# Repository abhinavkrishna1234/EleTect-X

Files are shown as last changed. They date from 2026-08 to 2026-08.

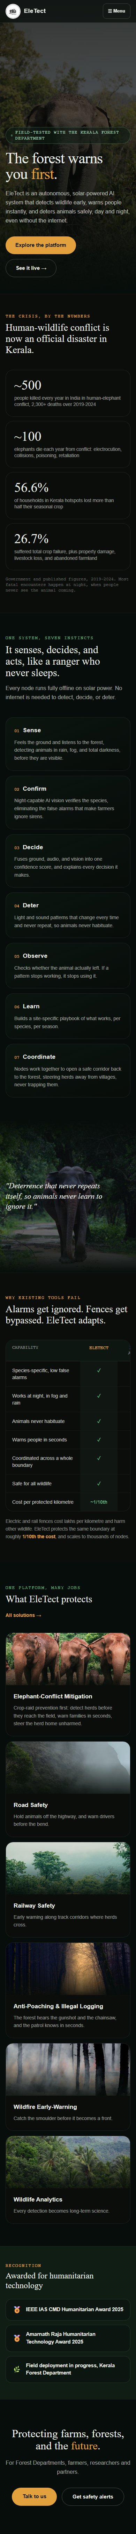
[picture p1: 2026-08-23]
docs/qa/phase2/home-built-mobile.png

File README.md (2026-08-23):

# EleTect X

**Adaptive Physical-AI platform for Human–Elephant Conflict (HEC) mitigation.**

EleTect X is a rugged, solar-powered, autonomous forest-edge node built on the Arduino UNO Q. It detects elephants early through the ground (seismic), confirms with on-device vision, deters with an adaptive, non-habituating light + sound response, alerts rangers, and coordinates with neighbouring nodes to steer wildlife safely — day and night, without cloud dependence.

## Why it's different
- **Seismic-primary, multimodal** detection (all-weather, day/night) — not a camera trap.
- **Adaptive deterrence** that measures outcomes and learns (contextual bandit), avoiding habituation.
- **Distributed coordination** — nodes create safe herding corridors, not random noise.
- **Ultra-low-power** event-driven architecture; weeks of autonomy.
- **Extensible** — optional environmental / fire-risk / anti-poaching pods; road-signage integration.

## Repository layout
| Path | Contents |
|---|---|
| `docs/` | Architecture, hardware, decisions (ADRs), deployment, manufacturing |
| `device/mcu/` | STM32U585 real-time reflex firmware |
| `device/mpu/` | QRB2210 (Debian) cognition: vision, fusion, deterrence, comms |
| `ml/` | Seismic/acoustic/vision model training + eval (off-device) |
| `hardware/` | PCB, CAD/enclosure, wiring |
| `web/backend/` | Supabase schema, RLS, edge functions |
| `web/ingest/` | ChirpStack MQTT → Supabase bridge |
| `web/frontend/` | Ranger dashboard + public marketing site (React PWA) |
| `deployment/` | Field protocols, install guides, logs |
| `scripts/`, `tests/` | Utilities and tests |

## Getting started
See [`CONTEXT.md`](CONTEXT.md) for the project's single source of truth, then [`docs/PROJECT_BLUEPRINT.md`](docs/PROJECT_BLUEPRINT.md) for the execution plan.

## Status
Active development. Architecture frozen; implementation in progress.

## License
Proprietary — see [`LICENSE`](LICENSE).

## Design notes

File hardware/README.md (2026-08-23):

# Hardware

pcb/ (KiCad), cad/ (enclosure STEP/STL + print profiles), wiring/ (pinouts, schematics).

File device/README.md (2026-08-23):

# Device — On-Node Software (Arduino UNO Q)

Everything that runs ON the node. `mcu/` = STM32U585 real-time reflex; `mpu/` = QRB2210 Linux cognition. Fully autonomous — no cloud in the control loop.

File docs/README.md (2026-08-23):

# Documentation

**Hierarchy (top → detail):** `CONTEXT.md` (canonical summary) → `docs/architecture/` + `docs/hardware/` (current design) → `docs/decisions/` (ADRs, the "why") → `docs/deployment/`, `docs/manufacturing/` (operational) → `docs/research/` (kept for reference) → `docs/archive/` (superseded, read-only).

**Rule:** exactly one current document per topic. If two disagree, `CONTEXT.md` wins; reconcile and archive the loser.

## Structure
| Folder | Holds | Status |
|---|---|---|
| `architecture/` | system, physical-AI, software, comms architecture | living |
| `hardware/` | BOM, camera, geophone, power, deterrence, enclosure specs | living |
| `decisions/` | ADRs (numbered), one per significant choice | append-only |
| `deployment/` | field-test protocol, KPIs, DFO, install guide | living |
| `manufacturing/` | DFM, in-house printing, assembly | living |
| `research/` | background studies still worth reading | frozen |
| `archive/` | obsolete / duplicated originals (dated) | read-only |

## Consolidation plan (migrate the existing research .md files)
The research phase produced many overlapping Markdown files. Consolidate as follows (one current doc per topic; everything else archived):

| Target (current) | Merge from |
|---|---|
| `CONTEXT.md` | Final Design Freeze + Pre-Build Optimization (decisions only) |
| `architecture/physical-ai.md` | Physical AI Architecture |
| `architecture/system.md` | Optimized Architecture + Rev B (UNO-Q-centric) + Rev B.1 (carrier-free) |
| `architecture/comms.md` | Connectivity Decision (LoRaWAN IN865) |
| `hardware/bom.md` | FINAL Freeze BOM |
| `hardware/camera.md` | Camera Shopping List + Comparison + IR-LED spec |
| `hardware/geophone.md` | Geophone Deployment Subsystem + Buy List |
| `hardware/deterrence.md` | Speaker Selection + Horn Analysis + Visual Deterrence Subsystem |
| `hardware/enclosure.md` | Concept Validation + Production Enclosure + In-House Manufacturing |
| `deployment/field-plan.md` | 45-Day Contest & Field Plan |
| `decisions/` (ADRs) | one ADR per frozen choice (camera, fusion, learning, comms, audio, geophone AFE) |
| `research/` | Ecological Framework, Confidence-Estimation study, Validation Report |
| `archive/` | all original Gemini deep-research drafts + any superseded review docs (prefix `YYYYMMDD-`) |

**Process:** (1) create the current docs above by lifting only the *decided* content; (2) move every original into `archive/` with a date prefix and a one-line "superseded by …" header; (3) never edit archived files. This yields a single source of truth that stays maintainable.

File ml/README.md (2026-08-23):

# ML — Off-Device Training

Training pipelines + datasets + evaluation. Runs on a PC, NOT the node. `seismic/` + `acoustic/` → **Edge Impulse** exports to `device/mcu/lib`; `vision/` → INT8 model to `device/mpu/models`. Keeps heavy training out of the flashable device code.

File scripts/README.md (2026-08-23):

# Scripts

Build/flash/calibrate/data utilities. No secrets committed.

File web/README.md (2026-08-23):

# Web — Monitoring Web App (off-device, not the control loop)

The Forest-Department web application. `frontend/` React PWA (dashboard + marketing); `backend/` Supabase (schema, RLS, functions); `ingest/` ChirpStack MQTT → Supabase. Renamed from 'cloud' to avoid implying on-device control — the node is fully autonomous; this only monitors/alerts.

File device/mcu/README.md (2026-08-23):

# MCU — STM32U585 (real-time reflex)

Arduino Core on Zephyr, C/C++. Geophone ADC+STA/LTA+**seismic TinyML**, **acoustic anti-poaching
(Edge Impulse, gunshot/chainsaw)**, actuator timing (horn/LED/IR), LoRa MAC, power, safety
rule-gates, watchdog. On-device models live in `lib/` (Edge Impulse SDK export).

## Two build paths — read this before touching either

- **`pio run -e native` / `pio test -e native`** — host-only compile/test harness (ADR 0010).
  Proves the whole `src/` tree builds and links against a small Arduino API shim
  (`hostshim/`), and runs the Unity known-answer tests on the pure cores (`sta_lta.cpp`,
  `rule_gate.cpp`). **This never produces a flashable image.** `hostshim/` is never synced to the
  board.
- **App Lab (or the Arduino App CLI over SSH)** — the only path onto real hardware. Fed by
  `scripts/sync-to-board.sh`, which one-directionally mirrors `src/` (config.h and secrets.h
  included — see the Layout section below on why they live in `src/`, not a separate `include/`)
  into the board's App folder as `sketch/`. Never hand-edit the board's copy — edit here, re-run
  the sync script, then build/flash from App Lab.

## Wiring — bench stand-in (ADS1115 + INA333)

The field geophone (SM-24) and its INA333 instrumentation amp connect to an ADS1115 breakout
today, standing in for the STM32's own internal ADC (ADR 0009 swaps this out via LPBAM once that
Rung lands). Plain jumper wires, not Qwiic — I2C2 is an independent bus from the Qwiic connector's
I2C4.

Pin names below match the actual silkscreen on the two breakout boards in use (INA333: `WCMCU-333`;
ADS1115: `HW-198`) — not the generic IC datasheet pin names, so this table can be followed directly
without translating labels at the bench.

**ADS1115 (`HW-198`) side:**

| Signal | ADS1115 pin (silkscreen) | UNO Q pin | MCU pin |
| --- | --- | --- | --- |
| SDA | `SDA` | D20 | PB11 (I2C2_SDA) |
| SCL | `SCL` | D21 | PB10 (I2C2_SCL) |
| Power | `VDD` | 3V3 | — |
| Ground | `GND` | GND | — |
| Address select | `ADDR` | GND | — (fixes I2C address at `0x48`) |
| Differential input+ | `A0` | — | INA333 `VOUT` |
| Differential input− | `A1` | — | INA333 `UREF` |

**INA333 (`WCMCU-333`) side:**

| Signal | INA333 pin (silkscreen) | Connects to |
| --- | --- | --- |
| Output | `VOUT` | ADS1115 `A0` |
| Reference | `UREF` | ADS1115 `A1` (same function as the datasheet's `REF` pin) |
| Power | `VCC` | 3V3 rail — use this pin, not the board's separate `3.3V` label (see note below) |
| Ground | `GND` | GND rail (either of the board's two `GND` pins) |
| Non-inverting input | `VIN+` | 1 kΩ series resistor → damping-resistor node → geophone lead |
| Inverting input | `VIN-` | 1 kΩ series resistor → damping-resistor node → geophone other lead |

**Unconfirmed:** this board breaks out both `VCC` and a separately labeled `3.3V` pin (also two `GND`
pins, one per edge). Most likely these are the same power/ground nets mirrored on both edges of the
board for breadboard convenience, not two distinct functions — but this is not verified against a
datasheet for this specific clone board. Wire `VCC` (the standard supply-pin name) to 3V3 and leave
the separate `3.3V` pin unconnected; only investigate further if the amp doesn't power up.

Geophone signal path: SM-24 → (1 kΩ damping resistor) → 1 kΩ series resistors → INA333 `VIN+`/
`VIN-` → INA333 → ADS1115 `A0`/`A1` differential pair, rejecting the INA333's bias rail (`UREF`)
rather than reading it as signal.

**Input protection — 1 kΩ in series with each INA333 input.** Between the damping-resistor node and
the INA333's `VIN+`/`VIN-` pins, add a 1 kΩ resistor in each leg. Negligible effect on the signal
(the INA333's input impedance is high enough that this forms an RC corner far above the 2-50 Hz
seismic band), but gives the amp's internal ESD structures some current limiting against a transient
on the buried cable run. Same 1 kΩ value as the damping resistor, already in the kit. This is a
cheap partial mitigation, not a substitute for the still-open TVS/clamp item in
`docs/KNOWN_GAPS.md` — see ADR 0001's 30 Jul addendum.

**Damping resistor — required, not optional.** The SM-24's open-circuit damping is h=0.25
(datasheet), badly underdamped at its 10 Hz resonance: an unshunted coil rings for several cycles
after every footfall, smearing the STA/LTA envelope the trigger detector reads. Wire a **1 kΩ
resistor directly across the SM-24's own two leads**, before the burial cable (not at the INA333
end — cable resistance would otherwise shift the delivered damping away from this calculation).
1 kΩ gives h≈0.69, matching one of the datasheet's own plotted response curves, using
`R_shunt = RtBcfn / (fn × (h_target − h_open)) − Rc` with the SM-24's own
`RtBcfn=6000 Ω·Hz, fn=10 Hz, Rc=375 Ω` against a target h≈0.7. Any resistor from the existing kit
works — tolerance isn't critical here. See ADR 0001 addendum for the full derivation.

**INA333 REF-bias check — do this before wiring the rest.** The geophone's output is a true AC
signal (swings both positive and negative). If the INA333's `UREF` pin is tied to GND instead of a
mid-supply bias (~VCC/2), the negative half of every waveform clips at the rail. Short `VIN+` to
`VIN-`, then run the check: set `GEOPHONE_DEBUG_SINGLE_ENDED_AIN0` to `1` in `src/config.h`,
sync, flash, and read the `[bias-check] raw=<int> volts=<float>` lines the board prints — ~1.65V
on a 3.3V rail means `UREF` is biased correctly and the wiring below is safe to use as-is; a
reading near 0V means it isn't, and needs an external fix before proceeding. Read the console via
**App Lab's own Serial Monitor (in a browser)** — `arduino-app-cli monitor` over SSH does not
deliver serial data on this board; see ADR 0010's 2026-07-30 addendum. Set the flag back to
`0` and re-sync before moving on — it must never read `1` on a node headed for the field
(`src/config.h`'s own bench-only-flags section says the same). Also check this board's `RG`
gain-setting pads (unlabeled in the photo reference for this specific board — look for a small
unpopulated 2-pad footprint near the INA333 chip itself, not on the main 8-pin header) — ~1 kΩ
gives a reasonable starting gain (G≈101) if bare.

**Result (2026-07-30):** `[bias-check] raw≈26890 volts≈1.6806V`, stable across multiple readings —
`UREF` is correctly mid-supply biased and the wiring above is safe to use as-is.

**Seismic waveform capture (Part C2 sensitivity pass).** Separate from the REF-bias check above:
set `SEISMIC_DEBUG_VERBOSE` to `1` to get a periodic `[seismic]` sta/lta/ratio line plus a
`[window]` CSV volts dump on every `[trigger]` event, then render the dumps with
`python scripts/plot_seismic_window.py <saved-console-log> --out-dir <dir>`. Same flag discipline
as above — back to `0` and re-sync once the capture session is done.

**Live seismic plot (pitch/demo tool, not the Part C2 pass above).** Set both
`SEISMIC_DEBUG_STREAM_RAW` and `SEISMIC_DEBUG_VERBOSE` to `1`, sync, flash, then run
`python scripts/live_seismic_plot.py --port <COM port>` (or `--file <log>` / `-` for stdin,
depending on which console transport is reachable — see the script's own docstring; only App
Lab's browser Serial Monitor is confirmed to deliver bytes at all, per ADR 0010's 2026-07-30
addendum) for a live two-panel view: raw geophone volts on top, STA/LTA ratio with the
`STA_LTA_TRIGGER_RATIO` (4.0) line on the bottom. The bottom panel does not advance for
`EVENT_MAX_MS` + `COOLDOWN_MS` (about 35 s today) after a trigger, since `[seismic]` only
prints while the state machine is in `kSensing` — time a recording around that gap rather than
expecting a continuous trace across an event. Same flag discipline as above — both flags back
to `0` and re-sync once the recording session is done.

**Known open item (`docs/KNOWN_GAPS.md`):** whether `Wire` or `Wire1` is actually the Arduino Core
mapping for I2C2 (D20/D21) on this board has not been confirmed on hardware. `config.h` defaults to
`Wire`. If the geophone never reads (`geophone_ok()` stays false, or `report_system_status`'s
`geophone_ok` field never sets), try `Wire1` first.

## Build / test

```powershell
cd device\mcu
pio test -e native      # both Unity suites: test_sta_lta, test_rule_gate
pio run -e native       # whole src/ tree compiles + links against the host shim
```

## Sync to board

```bash
# from the repo root, once the board is reachable over SSH (Network Mode)
scripts/sync-to-board.sh
```

Requires `src/secrets.h` to exist locally first (copy `src/secrets.h.example`, fill in the
real per-device OTAA DevEUI/AppEUI/AppKey — never commit this file, it's gitignored).

## Bench stomp test (Rung 1 exit criterion)

Run this after wiring the table above and syncing/flashing. **Set `SEISMIC_TRIGGER_CONSOLE_LOG` to
`1` in `src/config.h` first** — it defaults to `0` (`Serial` is shared with the E5 LoRa module now
that `LORA_SERIAL` is `Serial`; see `docs/KNOWN_GAPS.md`'s 18 Aug entry), so the `[trigger]` line
below stays silent unless this flag is on. Same discipline as `SEISMIC_DEBUG_VERBOSE`/
`SEISMIC_DEBUG_STREAM_RAW` above — flip it back to `0` and re-sync once the bench pass is done, it
must never read `1` on a node headed for the field.

1. Power the board and open App Lab's own Serial Monitor in a browser — `arduino-app-cli monitor`
   over SSH does not deliver serial data on this board (ADR 0010's 2026-07-30 addendum).
2. Let it idle ~30 s and confirm a quiet baseline: repeated STA/LTA sensing with no
   `[trigger]` lines, and (if logging is added later) a ratio staying comfortably under
   `STA_LTA_TRIGGER_RATIO` (4.0).
3. Stomp near the SM-24 geophone, firmly, a few times in a row.
4. Expect one line per crossing, in this exact format (emitted by `state_machine.cpp`):

   ```text
   [trigger] t=<ms> sta=<f> lta=<f> ratio=<f> idx=<n>
   ```

   `t` is `millis()` at detection, `sta`/`lta` are the mean-absolute-value short/long window
   values, `ratio` is `sta/lta`, `idx` is the sample index inside the window where the ratio
   peaked.
5. A failed sensor read looks like `geophone_ok()` reporting false (surfaced later via
   `report_system_status`) and an all-zero window — not a crash, per the schema's
   zero-fill-on-timeout contract. If every window reads as flat zero, check the `Wire`/`Wire1`
   question above before assuming the geophone itself is at fault.

**Status: done, 2026-08-14.** Run against real hardware on a lean field-flag build
(`SEISMIC_DEBUG_VERBOSE` temporarily set to 1 for the pass to get quantified quiet-floor
numbers alongside the trigger, then reverted to 0 immediately after). Quiet floor held a
ratio of 1.03–1.13 across ~89 s (before and after the stomp, no false triggers); a firm
stomp near the geophone produced `ratio=4.60`, with the `[window]` CSV dump confirming a
real ~65x amplitude transient over the noise floor. `STA_LTA_TRIGGER_RATIO` (4.0) clears
the observed floor ceiling by ~3.5x and the stomp clears the threshold by ~15% — see
`docs/KNOWN_GAPS.md`'s 2026-08-14 entry for the full write-up. `STA_LTA_DETRIGGER_RATIO`
was never validated this way and was removed 2026-08-15 as dead code — `kEvent` only ever
exits on `EVENT_MAX_MS` elapsed, never a ratio; see `docs/KNOWN_GAPS.md`'s 2026-08-15 entry.

**Multi-trial follow-up: done, 2026-08-15.** 12 stomps at 60 s intervals against the same
lean-flag-toggle build; 11/12 detected (mean trigger ratio 4.232, stdev 0.166), one genuine
sub-threshold miss (peak ratio 3.80) explained rather than dismissed, zero false triggers
across a 688-sample quiet baseline (mean ratio 1.149). MPU-side `report_footfall_event` fired
for all 11/11 triggers with matching `sta_lta_ratio` and `fused_P` 0.979–0.986 — confirmed via
the board's raw Docker json-log (`docker logs` itself fails on this container with a stream
corruption error; see `docs/KNOWN_GAPS.md`'s 2026-08-15 multi-trial entry for the workaround
and full statistics).

## Layout

```text
src/                        flat - no subfolders (see rationale below)
  sketch.ino               required by arduino-cli's naming convention only - empty otherwise
  sketch.yaml              required by arduino-app-cli - board profile, not repo-specific
  config.h                 pin map + tuning constants
  secrets.h / secrets.h.example   per-device OTAA credentials (secrets.h gitignored)
  main.cpp                 setup()/loop() shell
  state_machine.{h,cpp}    idle -> sensing -> event -> cooldown
  geophone.{h,cpp}         read_seismic_window() over the ADS1115 stand-in
  sta_lta.{h,cpp}          pure STA/LTA core, zero hardware calls
  rule_gate.{h,cpp}        pure clamp/cooldown core, shared by horn/led/ir
  horn.{h,cpp}             owns AUDIO_TRIGGER_PIN + HORN_AMP_ENABLE_PIN
  led.{h,cpp}              white/blue deterrent LED pods
  ir.{h,cpp}               940nm illuminator for night-vision capture
  mac.{h,cpp}              Grove E5 AT-command OTAA join (IN865 only)
hostshim/        HOST BUILD ONLY - never synced to the board (ADR 0010)
tests/           Unity known-answer suites (pure cores only)
```

`src/` is deliberately flat — no `sensors/`/`actuators/`/`footfall/`/`lora/` subfolders, and
`config.h`/`secrets.h` live directly in it rather than a separate `include/`. This is load-bearing,
not stylistic (ADR 0010's addendum has the full story): `arduino-cli`'s sketch build only compiles
`.cpp` files that are direct children of the sketch root, and only puts the sketch root itself on
the include search path — subfolder `.cpp` files are silently skipped (the build reports zero
errors, then fails at the link step), and a subfolder file's bare `#include "config.h"` only ever
worked by accident under PlatformIO's now-removed `-I include` flag. App Lab's build has no
equivalent fallback for either case. Every file in `src/` therefore sits at the same depth and uses
a plain `#include "whatever.h"` — no relative `../` paths anywhere in this tree.

`sketch.ino` is a separate, unrelated requirement from the same tool: `arduino-cli` refuses to
compile a sketch at all unless it contains a file named exactly `<sketch-folder-name>.ino` — on the
board that folder is always `sketch/` (see `scripts/sync-to-board.sh`), so this file must be named
`sketch.ino` regardless of this repo's own directory name. It carries no logic; `setup()`/`loop()`
are ordinary functions in `main.cpp`, which the merged sketch links against normally. Do not delete
it — a manual `rm -rf` of the board's `sketch/` folder without this file present breaks the build
with `main file missing from sketch`, and it will not be restored by re-running
`scripts/sync-to-board.sh` unless it exists here in the repo first.

`sketch.yaml` is the same story from `arduino-app-cli` rather than `arduino-cli`: `app start`
refuses to run at all without it present (`sketch folder is incomplete: both sketch.ino and
sketch.yaml are required`), and it carries no repo-specific content — just the `arduino:zephyr`
platform profile every App Lab sketch uses. Like `sketch.ino`, it belongs here rather than only on
the board for the same `rsync --delete` reason.

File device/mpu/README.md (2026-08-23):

# MPU — QRB2210 (event cognition, Debian/Python)

Vision detector (Adreno/OpenCL), log-odds fusion, contextual-bandit deterrence, SQLite experience,
Bridge RPC, LoRa uplink. On-device vision model in `models/`. Bridge function signatures are
frozen against [bridge/schema.md](bridge/schema.md) — that file, not this README, is the source of
truth for what each function does; both sides (`device/mcu`, here) are hand-written against it
independently (`ENGINEERING_CONVENTIONS.md` §6).

## Two build paths — read this before touching either

- **`ruff check .` / `pytest -q`** — host-only lint/test harness. `pyproject.toml` has no runtime
  dependency on `arduino.app_utils` (the module that provides `Bridge`) — it only exists on the
  QRB2210's own Python install, so nothing under `bridge/`, `perception/`, `cognition/`, or
  `services/` may import it at module scope. This never produces a running App.
- **App Lab (or the Arduino App CLI over SSH)** — the only path onto real hardware. Fed by
  `scripts/sync-to-board.sh`, which one-directionally mirrors this tree (minus `tests/`, `bench/`,
  `pyproject.toml`, `__pycache__/`) into the board's App folder as `python/`. Never hand-edit the
  board's copy — edit here, re-run the sync script, then build/run from App Lab.

## Build / test

```powershell
cd device\mpu
ruff check .
pytest -q
```

## Sync to board

```bash
# from the repo root, once the board is reachable over SSH (Network Mode)
scripts/sync-to-board.sh
```

Syncs both `device/mcu` and `device/mpu` into the real `EleTect-X` App. The disposable ping bench
below is a separate App and is **not** covered by this script — see its own procedure.

## Layout

```text
bridge/
  schema.md      Bridge contract — source of truth for every function below
  rpc.py         signatures + docstrings for all 8 schema.md functions, no Bridge wiring yet
perception/
  camera.py      IMX462 V4L2 capture wrapper — open/capture/burst/release, no trigger/IR logic
  (vision INT8 detector itself: future build call)
cognition/
  fusion.py      weighted log-odds fusion (CONTEXT.md 4) — pure function, no Bridge/hardware
  decision.py    alert gate on the fused probability — pure function
  bandit.py      epsilon-greedy tier selection + habituation floor — pure, RNG injected
  experience.py  SQLite experience store (triggers/attempts/action values), the only I/O here
  config.py      fusion weights + bandit hyperparameters and tier ladder — one rationale each
services/
  config.py      MPU-side tuning constants, one rationale each (mirrors device/mcu/include/config.h)
comms/           LoRa uplink (future build call)
models/          on-device vision model export, gitignored (*.tflite)
tests/           host-only contract + config tests, never synced to the board
bench/ping/          disposable hello-world Bridge round trip, see below
bench/camera_check/  disposable camera capture-and-save check, see below
bench/demo_replay.py host-only replay of both reflex-loop entry points, see below
```

`bridge/rpc.py` ships as **signatures and docstrings only**, deliberately not wired up with
`Bridge.provide()` — `DEVICE_DEVELOPMENT_WORKFLOW.md` §3 documents a live, reproducible bug where
registering an extra `Bridge.provide()` function broke every previously-working function on the
same sketch. The practical discipline that earns: register one function at a time on real
hardware, testing between each addition, not a batch of eight from a host build with no board
attached. The MCU side observes the same caution (`device/mcu/src/main.cpp`).

## Ping bench — hello-world Bridge round trip (MCU → MPU direction)

Rung 0 proved a Bridge round trip **Python → MCU** (the stock Blink LED example — Python toggling
a GPIO the MCU sketch drives). Nothing has yet proven the reverse: **MCU → Python**, which is the
direction every MCU→MPU `notify` in `bridge/schema.md` needs (`report_footfall_event`,
`report_acoustic_event`, `report_system_status`). `bench/ping/` is a complete, disposable App Lab
app that exercises exactly that — one `Bridge.call("ping", token)` from the MCU sketch every 2 s,
answered by exactly one Python-provided function. It is deliberately separate from the real
`EleTect-X` App and from `bridge/rpc.py`'s schema stubs: nothing here is schema-shaped, and it must
never be merged into the real App.

**Why `call` and not `notify`, even though the real schema functions this direction use `notify`:**
`Bridge.call()` returns a verifiable `pong` reply, which is the better bench test — a `notify` firing
silently gives no positive confirmation it was received at all. See the precision note in
`docs/KNOWN_GAPS.md` about exactly what this bench does and does not prove.

### Prerequisites

- Board reachable over SSH in Network Mode (`DEVICE_DEVELOPMENT_WORKFLOW.md` §2).
- No other App using the same Bridge socket registered with a conflicting `ping` name.

### Running it

1. Push the bench app to the board (not covered by `scripts/sync-to-board.sh` — a plain one-liner,
   since this app is throwaway):

   ```bash
   rsync -avz device/mpu/bench/ping/ arduino@<board-host>:/home/arduino/ArduinoApps/ping-bench/
   ```

2. Open the app in App Lab (or `ssh` in and use the Arduino App CLI) and build/run it.
3. Watch the console. A successful round trip looks like this, repeating every 2 s:

   ```text
   MCU:  [ping] sent token=<n>
         [ping] reply=pong:<n> rtt=<ms>
   MPU:  [ping] token=<n> -> pong:<n>
   ```

   `<n>` matches on both lines for a given round trip; `rtt` is the MCU-observed round-trip time in
   milliseconds.

### If it doesn't build or the reply never arrives

Three details in `sketch/main.cpp`, `python/main.py`, and `app.yaml` are marked
`// UNVERIFIED` / `# UNVERIFIED` inline — written from `DEVICE_DEVELOPMENT_WORKFLOW.md` §3's
description of the Bridge API, not checked line-by-line against a real generated App. If the sketch
won't compile or the reply never arrives, diff against the stock Blink LED example (confirmed
working on this board at Rung 0) before assuming the Bridge itself is broken — it is more likely one
of these three unverified details than a fundamental Bridge failure.

**Status: pending hardware.** This procedure has not yet been run against real hardware — see
`docs/KNOWN_GAPS.md`.

## Camera bench check — capture-and-save against the real IMX462

`perception/camera.py` is a pure V4L2 capture wrapper (`ENGINEERING_CONVENTIONS.md` §1's earned
`capture_frame()` interface boundary) — fully unit-tested against a fake capture device
(`tests/test_camera.py`), but never yet run against the real Arducam IMX462 (ADR 0001).
`bench/camera_check/capture_check.py` is a disposable, non-App-Lab script (needs no Bridge, no
`app.yaml`) that opens the real camera, captures one frame plus a short burst, saves them to disk,
and prints exactly what the device negotiated — resolution, pixel format, and FPS — which is what
turns `docs/KNOWN_GAPS.md`'s IMX462-defaults entry from an assumption into a measured fact.

It runs in two places, both driving the same `perception.camera.Camera` class:

- **The board**, over SSH, the actual V4L2/target-platform path (`--backend v4l2`, or the
  `--backend auto` default, which resolves to V4L2 on Linux).
- **A Windows/macOS dev host** with `pip install opencv-python` (not a `pyproject.toml` dependency —
  see "Two build paths" above), using `--backend any` (or `auto`'s off-Linux default) — the IMX462
  is a UVC device, so DirectShow/AVFoundation see it too. Useful for confirming the physical camera
  works *before* a board session is available; the V4L2 path itself stays pending hardware either
  way.

### Camera check prerequisites

- **Board run:** board reachable over SSH in Network Mode; camera plugged into the board's USB-C
  port via the spare USB hub (`hardware/bom/procurement-status.md`) — the port can't be both a dev
  link and a camera host at the same time, so run this over Network Mode, not a USB dev cable; and
  `python3-opencv` present on the board's Debian image (unverified — `docs/KNOWN_GAPS.md`).
- **Host run:** `pip install opencv-python` and the IMX462 plugged into a USB port directly.

### Running the camera check

Board (not covered by `scripts/sync-to-board.sh` — a plain rsync one-liner, same as the ping
bench):

```bash
rsync -avz --exclude='__pycache__' device/mpu/ arduino@<board-host>:/home/arduino/camera-check/
ssh arduino@<board-host> "cd /home/arduino/camera-check && python3 bench/camera_check/capture_check.py --probe"
```

Dev host (from the repo root, camera plugged in):

```powershell
python device\mpu\bench\camera_check\capture_check.py --backend any --out-dir <scratch-dir>
```

### What a successful capture looks like

```text
Opening '/dev/video0' (backend=auto, requested 1920x1080 MJPG)...
Negotiated: device=/dev/video0 1920x1080 fourcc=MJPG fps=30.0

Single frame:
  saved output\single.jpg (187342 bytes, index=0, t=1.203s)

Burst (5 requested):
  saved output\burst_00.jpg (183210 bytes, index=0, t=1.245s)
  saved output\burst_01.jpg (185004 bytes, index=1, t=1.279s)
  saved output\burst_02.jpg (184556 bytes, index=2, t=1.312s)
  saved output\burst_03.jpg (186012 bytes, index=3, t=1.347s)
  saved output\burst_04.jpg (183890 bytes, index=4, t=1.381s)
  inter-frame intervals (s): [0.034, 0.033, 0.035, 0.034]

Done. 6 frame(s) saved to output
```

Non-trivial file sizes (tens to hundreds of KB, not near-zero) and a `Negotiated:` line matching
real numbers, not the requested ones, are the two signals that this is a real frame, not a
black/garbage capture. **Expected resolution/format is 1920×1080 MJPG — that is the product
listing's stated spec, not yet confirmed against this specific unit** (`docs/KNOWN_GAPS.md`).

### If no `/dev/video*` node shows up

Run `--probe` first — it lists `/dev/video*` nodes and, if `v4l2-ctl` is installed, the camera's
full format list. A completely empty listing with the camera physically plugged in points at a USB
host-mode question (does the UNO Q's USB-C port enumerate a host device at all while powered from
VIN?), not a bug in `capture_check.py` or `camera.py` — see `docs/KNOWN_GAPS.md`.

**Status: pending hardware.** Written and host-tested against a fake capture device; not yet run
against the real IMX462 on the board or the dev host.

## Demo replay — both reflex-loop entry points, no hardware

`bench/demo_replay.py` runs two passes against the real `services/reflex_loop.py` — no board,
camera, or Bridge involved either way.

**Pass 1 (seismic, real bench data)** feeds `handle_footfall_event()` — the actual sense → fuse →
decide pipeline, not a mock of it — the real STA/LTA ratios and fused probabilities
`docs/KNOWN_GAPS.md`'s "Multi-trial stomp validation protocol" entry captured on real hardware on
2026-08-15 (12 stomps, 11 detected, one genuine sub-threshold near-miss), and narrates each step to
the terminal. The actuator/camera callables passed in raise if ever called, since this always runs
`safe_mode=True`.

**Pass 2 (acoustic routing, illustrative)** calls the real `handle_acoustic_event()` once per
`AcousticClass` value, to make ADR 0007 §5's three-way routing split (landed alongside this pass)
watchable rather than just provable: gunshot bypasses `fuse()` entirely and prints the real
`[SAFE_MODE]` alert line the event actually logged (captured from the real logger, not re-typed);
chainsaw/vehicle/animal_call fuse as one shared ACOUSTIC modality and print the live `fused P`,
identical across the three; ambient fuses as unavailable, with `acoustic` visible in
`fusion.dropped`. Every input in this pass uses one fixed synthetic confidence, 0.87 — **this is not
captured bench data**, unlike pass 1: no acoustic classifier runs on the MCU yet, so there is nothing
real to replay. Only the inputs are synthetic; the routing, the fusion and every printed number come
from the real function call.

Built for the Robu bench demo, where the actuators aren't wired to the board yet.

### Running the demo replay

```powershell
cd device\mpu
python bench\demo_replay.py
```

`--interval <seconds>` controls the pause between events in both passes (default 1.5s, for demo
pacing — pass 0 to run flat out). `--no-color` disables ANSI styling for a plain terminal or a log
capture.

### What it proves

Every printed `fused P(elephant)` in pass 1 is computed live by the real `fuse()`/`decide()` call and
printed next to the real fused probability the board actually logged that day — they match to the
displayed precision, which is the script's own check that its replicated on-MCU probability formula
(`footfall_features.cpp`'s saturating fit) is right, not an assertion to take on faith. The closing
summary reproduces the real run's 11/12 detection rate and 11/11 alert rate. Each alert also prints
the tier the real bandit selected and the repeat count that drove it, so the escalation ladder is
visible on replayed data — the replay injects an in-memory experience store, so it never writes
learning state and never touches `data/experience.sqlite3`.

Pass 2 proves the routing split itself executes as ADR 0007 §5 describes it — three distinct routes,
one alert path that skips fusion, one shared modality for three classes, one dropout case — on live
calls, not on hand-typed numbers. It proves nothing about real-world acoustic classifier accuracy or
confidence calibration; the confidence value is fixed and synthetic.

**Status: closed.** Runs clean against the real `cognition`/`services` modules (`pytest -q`: 217
passed), no hardware required.

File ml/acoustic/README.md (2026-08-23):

# Acoustic classifier — five-class model, real public data (not yet trained)

Edge Impulse project **1094275** (`EleTect-X-Acoustic`), separate from `EleTect-X-Seismic`
(1094084) and `EleTect-X-Vision` (1094260). Project ID only is recorded here; the API key is not
in the repo and must be supplied through `EI_API_KEY` at run time.

**Status: the upload and training scripts are written and code-complete, but neither has run against
a live Edge Impulse project yet.** Two of the four acquisition paths were verified for real against
their live sources: ESC-50's `meta/esc50.csv` was fetched for real (confirmed all 40 chainsaw clips,
correct 32/8 fold split) and 2 real chainsaw clips were downloaded and normalized end-to-end —
8 kHz, exactly 4.0 s, byte-exact. Mendeley's public-api endpoint, however, is currently answering
with a **persistent Cloudflare bot-challenge** (HTTP 403, `Cf-Mitigated: challenge`) instead of the
dataset JSON, reproduced across several attempts minutes apart — a live external block on Mendeley's
side right now, not a bug in this script (`scripts/edge_impulse_upload_acoustic.py`'s `_get()`
detects and reports this case distinctly from an ordinary HTTP error). Freesound's two classes need
a `FREESOUND_API_KEY` — a free credential that has to be created by hand at
<https://freesound.org/apiv2/apply/> — which does not exist yet. Nothing below is a fabricated
number: the Dataset section states real, verified counts and licenses pulled from each source's own
API or metadata file; the Result section says plainly that no training run has happened yet rather
than inventing one.

## Dataset

Four distinct public sources feed the five `AcousticClass` labels
(`device/mpu/bridge/rpc.py`):

| Class | Source | License (verified) | Count (planned) |
|---|---|---|---|
| `gunshot` | Mendeley Data `x48cwz364j` v3, "Tropical forest gunshot classification training audio dataset" (Katsis et al. 2022, DOI 10.17632/x48cwz364j.3) | **CC BY 4.0** — confirmed via the dataset's own `data_licence` field in its public API record, not assumed from Mendeley's common default | 747 (597 train / 150 test, the authors' own two folders) |
| `ambient` | same Mendeley dataset, background-noise folder | CC BY 4.0, same record | up to 150, seeded subsample of 7,040 available |
| `chainsaw` | ESC-50, ESC-10 subset (Piczak 2015, DOI 10.1145/2733373.2806390), `meta/esc50.csv` rows with `category == "chainsaw" and esc10 == True` | **CC BY** — the ESC-10 subset only; the rest of ESC-50 is CC BY-NC and is never touched | 40 (all of them; 32 train / 8 test by the dataset's own `fold` column) |
| `vehicle` | Freesound.org, text search `"engine idling"` | Per-clip CC0 or CC BY, recorded individually per clip | up to 150, seeded subsample |
| `animal_call` | Freesound.org, text search `"elephant"` | Per-clip CC0 or CC BY, recorded individually per clip | up to 150, seeded subsample |

### Gunshot and ambient — Mendeley `x48cwz364j` v3

The dataset's own description claims 749 gunshot files and "over 35,000" background files. The
public API's actual file listing (7,788 entries total) holds 747 gunshot files across two folders
(597 + 150 — 79.9% / 20.1%, matching the description's stated 80/20 split by count) and only 7,040
loose background WAVs plus one 1.3 GB `background.zip` holding the rest. The 2-file gunshot gap
against the stated 749 is a real discrepancy between the dataset's description and its own file
listing, not a bug in this project's tooling — it is logged by the upload script, not hidden.

All 747 available gunshot clips are used, uncapped. It is real, rare, transient positive-class data
and there is no principled reason to throw part of it away for a tidier class balance; Edge
Impulse's automatic class weighting compensates for the resulting imbalance against the other four
classes at training time instead.

`background.zip` is skipped entirely and never downloaded — at 1.3 GB it would imply roughly
28,000 more files than the 7,040 loose ones, meaning it is almost certainly the larger, 80% share of
the background set, and downloading it just to throw away all but a ~150-clip subsample is not
worth 1.3 GB of transfer. This means the ambient class draws from only one of the authors' two
background folders, not both — see Caveats.

The gunshot class uses the authors' own two folders as its train/test split (temporally distinct
collection sessions, per the dataset's description — a stronger split than a random one). Ambient
has no second folder to play that role, so this project draws its own seeded (`SPLIT_SEED = 20260823`)
subsample and its own chronological split (filenames are UNIX-hex timestamps, sorted before
splitting) from inside the single available folder instead.

### Chainsaw — ESC-50 ESC-10 subset

All 40 ESC-50 clips tagged `category == chainsaw` already carry `esc10 == True` — the entire
chainsaw category is inside the CC BY-licensed ESC-10 subset, none of it needs excluding. Split by
the dataset's own `fold` column (folds 1–4 training = 32 clips, fold 5 testing = 8 clips), which
already keeps clips sharing a `src_file` inside a single fold rather than this project having to
re-derive that grouping itself.

### Vehicle and animal_call — sourced from Freesound, not the originally named sources

Three sources named for this task were checked against their live pages/APIs before any data was
pulled, and none of them held up:

- **UrbanSound8K** — originally specified for `vehicle` (`engine_idling`), filtered per-clip to
  CC0/CC BY. Its own metadata CSV (`slice_file_name, fsID, start, end, salience, fold, classID,
  class`) carries **no license column at all**, and the dataset's Zenodo record (1203745) and
  README both declare the entire distribution **CC BY-NC 4.0**. There is no CC0/CC BY subset
  inside it to filter to — the per-clip filtering this task was originally scoped around cannot be
  executed against real metadata that doesn't exist, so UrbanSound8K is not used at all.
- **Michael Pardo's elephant-rumble records** — originally specified as an `animal_call` candidate.
  Zenodo record 10576772 is a single R script (LGPL license) whose own description states "the
  sound files ... are not included in this archive"; the paired Dryad record
  (doi:10.5061/dryad.hmgqnk9nj) is derived CSV/RDS acoustic-feature tables carrying the same
  disclaimer. Neither contains a single audio file.
- **`github.com/HiruDewmi/Audio-Classification-for-Elephant-Sounds`** — the other named
  `animal_call` candidate. Real, curated Rumble/Roar/Trumpet WAV files do exist in its `data/`
  tree, but the repository has no `LICENSE` file, no terms stated in its README, and no
  attribution for where the original recordings came from — GitHub's own repository API reports
  `license: null`. Real audio with no usable license is not usable audio for this project.

Both classes are instead pulled directly from Freesound.org's search API
(`/apiv2/search/text/`), filtered to Freesound's own license facets `"Creative Commons 0"` or
`"Attribution"` only — **CC BY-NC and every other Freesound license are excluded** — with each
selected clip's own id, uploader, license and URL recorded individually in
`dataset_manifest.json`, rather than a blanket license inherited from a dataset as a whole.
Freesound's `/download/` endpoint (the original uploaded file) requires OAuth2 (verified:
returns HTTP 401 with only a token); token authentication reaches the public 128 kbps MP3
preview instead, so vehicle and animal_call audio is transcoded from Freesound's lossy preview
file, not the original upload. Freesound relevance is **uploader tagging, not expert
verification** — see Caveats.

### Normalization (all four sources)

- **8000 Hz mono**, matching Mendeley's native rate — the lowest of the four sources, so every
  other source is downsampled and none is upsampled. Resampling uses
  `scipy.signal.resample_poly` (anti-aliased), not stdlib `audioop.ratecv`: `ratecv` has no real
  anti-alias filter, and decimating ESC-50/Freesound's 44.1 kHz at roughly 5.5:1 without one folds
  high-frequency energy back down into exactly the low mel bands the DSP block reads — that would
  corrupt every non-Mendeley class's frequency content, not just add broadband noise.
- **4.0 seconds per clip**, centre-cropped or zero-padded. Chosen because it sits just under
  Mendeley's native 4.09 s clip length, so gunshot — whose transient position inside its clip is
  not annotated anywhere in the dataset — is never cropped and can never have its transient cut
  off; every other, shorter or longer, source is trimmed or padded to meet that length instead.

## Impulse

- **Input** (block 1): time-series, 1 axis (`audio`), 8000 Hz declared, 4000 ms window, 4000 ms
  stride (no overlap — one window per clip, so no window can span two clips or mix a class label
  with padded-in silence from a shorter source clip), zero-pad on.
- **DSP** (block 2): **MFE** (mel-filterbank energy), not MFCC. MFCC's cepstral truncation is
  built for speech, where the fine spectral detail it discards is formant structure a listener
  doesn't need. Here that same detail is exactly what separates a gunshot's broadband transient
  shape from a chainsaw's harmonic engine whine — both classes need the full mel-band energy
  profile MFE keeps, not MFCC's compressed cepstral coefficients. Spectrogram was the fallback if
  MFE underperformed. Block parameters are read back live and printed by the training script
  rather than asserted from documentation; none are overridden from their defaults.
- **Learn** (block 3): Keras classification, five classes, automatic class weighting (gunshot's
  747 against chainsaw's 40 is a real, reported imbalance — see Caveats), INT8 quantization
  profiled (`profileInt8: True`) to match this project's Cortex-M33 deployment target.

## Result

**Not yet trained.** Running `scripts/edge_impulse_upload_acoustic.py` requires
`FREESOUND_API_KEY` (not yet created) in addition to `EI_API_KEY` / `EI_PROJECT_ID`, and both
scripts require real internet access to Mendeley, GitHub and Freesound that this pass did not
have. This README will be updated with the real per-class held-out numbers — reported separately,
never averaged into one figure, since gunshot / chainsaw / vehicle / animal_call / ambient come
from four different recording contexts and four different sets of equipment and are expected to
perform unevenly — once both scripts have actually been run against a live project.

## Caveats — required whenever any number from this project is quoted

1. **None of this audio was captured on this project's own INMP441, and none of it is from Kerala
   forest conditions.** Every class comes from other researchers' or other users' recordings —
   different locations, different equipment, different years. This closes *"a 5-class acoustic
   model exists and is trained on real, licensed data,"* **not** *"this model works on real field
   audio from this project's own microphones."* Those two claims travel separately, and only the
   first one is true after this work.
2. **The elephant-rumble low end is not actually captured.** Rumble fundamentals sit at roughly
   8–34 Hz, well under the 8 kHz sample rate's Nyquist limit — but Nyquist was never the binding
   constraint. An MFE block's lowest mel band sits far above 34 Hz, so the model sees rumble
   harmonics and overtones, never the fundamental. This is consistent with the project's
   architecture rather than a defect in this pass — `/CONTEXT.md` scopes the INMP441 to
   frequencies above 60 Hz and gives low-frequency detection to the geophone instead — but it
   means `animal_call` here is not infrasound detection, regardless of how well it scores.
3. **Freesound clip relevance rests on uploader tagging, not expert verification.** There is no
   guarantee every clip returned for the `animal_call` query is actually an elephant rather than
   an unrelated recording that happens to be tagged or titled that way; clips were filtered by
   license, tag and duration, not listened through individually.
4. **Chainsaw is n=40 against up to 150 for every other class.** Its per-class number has to be
   read against that sample size, not compared at face value to the larger classes'.
5. **Ambient's train/test split is weaker than gunshot's.** Gunshot's two folders are the authors'
   own temporally-distinct collection sessions. Ambient only has one usable folder (see Dataset
   above), so its split is this project's own seeded chronological cut inside that one folder —
   not two independently-collected sets the way gunshot's are.
6. **Vehicle and animal_call are transcoded from Freesound's lossy 128 kbps MP3 preview, not the
   original uploaded file** (the original requires OAuth2, which this script does not implement).
7. **Not deployed.** No acoustic inference runs on this project's hardware. This closes the
   training half of the gap `docs/KNOWN_GAPS.md` records, not the deployment half — see that
   file's separate entry for exporting this model and wiring it into
   `handle_acoustic_event()`.

## Reproducing

```
export EI_API_KEY=ei_...          # project 1094275 API key, not stored in this repo
export EI_PROJECT_ID=1094275
export FREESOUND_API_KEY=...      # create at https://freesound.org/apiv2/apply/
python scripts/edge_impulse_upload_acoustic.py
python scripts/edge_impulse_train_acoustic.py
```

`ml/datasets/acoustic/raw/` (gitignored) caches downloaded and normalized audio so a re-run does
not re-fetch or re-query Freesound; `dataset_manifest.json` in this directory is committed and
records the exact clip selection — source, license, split, sha256 of the normalized payload — so
the dataset behind any future reported number is reproducible from a fresh clone even though the
raw audio itself is not, and even though a live Freesound search could return different results on
a later run.

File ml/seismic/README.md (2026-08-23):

# Seismic footfall classifier — first trained model (proof of concept)

Edge Impulse project **1094084** (`EleTect-X-Seismic`). Project ID only is recorded here; the API
key is not in the repo and must be supplied through `EI_API_KEY` at run time.

**Read the caveats section before quoting the accuracy number anywhere.** This is a genuine model
trained on genuine hardware captures, and it is also a 12-event proof of concept. Both halves of
that sentence have to travel together.

## Dataset

`bench_windows_20260814_15.json` holds the **12 real 512-sample geophone windows** captured during
the 14/15 Aug bench stomp sessions (SM-24 → INA333 → ADS1115, one person stomping near one geophone
on one bench). Values are raw volts, exactly as logged. Each event carries its source log, capture
timestamp, STA/LTA trigger ratio and trigger index, and a sha256 of its own values.

The raw session logs live in `scripts/bench-logs/`, which is **gitignored** — hence this artifact.
`scripts/edge_impulse_upload_seismic.py` reads the logs when present and falls back to this file
otherwise, and the two paths were verified to produce byte-identical samples, so the dataset behind
the number below is reproducible from a fresh clone.

Each event is split into two honestly-labeled segments, no synthesis anywhere:

| Label | Segment | Length | Why it is real |
|---|---|---|---|
| `quiet` | first 128 samples | 512 ms | Pre-event ambient. Every logged trigger has `idx=511`, so the transient is always at the last sample and never intrudes here. |
| `footfall` | last 64 samples up to the trigger | 256 ms | The actual captured stomp transient. |

24 samples total, split by event so no event appears on both sides: **9 events (18 samples)
training, 3 events (6 samples) testing.**

## Impulse

- **Input** (block 1): time-series, 1 axis `geophone_v`, 250 Hz declared, 256 ms window, 256 ms
  stride, zero-pad on. 256 ms is exactly the footfall segment length, so no positive example is
  padded; a non-overlapping stride splits each 512 ms quiet segment into two windows rather than
  inflating the count with overlapping ones. Yields **27 training windows** (9 footfall, 18 quiet)
  and **9 testing windows** (3 footfall, 6 quiet).
- **DSP** (block 2): spectral analysis. Two parameters were moved off their defaults, both
  disclosed here because they were chosen, not inherited:
  - `spectral-power-edges = 5, 10, 20, 40, 80` Hz. The stock `0.1–5` Hz edges are accelerometer
    defaults and put every bin below the SM-24's 10 Hz natural frequency; 80 Hz stays under the
    125 Hz Nyquist of the declared rate.
  - `scale-axes = 1000`, i.e. volts → millivolts. A pure unit change, not a tuning knob — see the
    convergence note below for why it was needed.
  - `filter-type = none`, `fft-length = 16` (defaults, unchanged).
- **Learn** (block 3): Keras classification over `quiet`/`footfall`. 200 training cycles, learning
  rate 0.005, 20% validation split, automatic class weights (the windowing leaves a 2:1
  quiet:footfall imbalance).

## Result

Held-out test set, run as an Edge Impulse model-testing job over the 3 testing events the model
never saw in any form:

**9 / 9 windows classified correctly — 100% accuracy, 0 uncertain.** Per-window confidence in the
true class ranged 0.9455 to 1.0000 against a 0.6 minimum-confidence threshold. Confusion matrix is
diagonal: footfall 3/3, quiet 6/6.

The classes turn out to be trivially separable at this scale, which is worth stating plainly rather
than dressing up: measured directly from the committed windows, quiet RMS averages 1.34e-4 V
(max 1.89e-4) and footfall RMS averages 2.93e-3 V (min 2.29e-3) — a 12× gap with **zero overlap**
between the two sets. A single RMS threshold would separate this dataset perfectly. The trained
model is not doing anything a judge should assume is subtle.

## Caveats — required whenever this number is quoted

1. **n = 12 events.** The test set is **3 events / 6 samples / 9 windows**. Accuracy off 9 windows
   has ~11% granularity: one misclassified window would read as 89%.
2. **Not independently sampled.** The `quiet` and `footfall` segments come from the *same* 12
   recordings, so the two classes share their recording conditions exactly.
3. **One person, one geophone, one bench, two sessions.** No elephants, no field conditions, no
   coupling variation, no negatives other than each recording's own pre-event ambient. Nothing here
   establishes behaviour against rain, vehicles, cattle, or distance.
4. **Sample rate is declared, not measured.** 250 Hz nominal was uploaded; `docs/KNOWN_GAPS.md`
   measured 226.98 Hz on a lean field-flag build. This scales the frequency axis of the DSP block
   only — it does not touch the sample values or the accuracy figure, but the spectral edges are
   nominal-Hz edges.
5. **Not deployed.** This model does not run on the MCU and does not replace
   `footfall_features.cpp`'s placeholder `x²/(x²+c²)` probability. Nothing in the field path uses it
   yet.

Correct framing for a report table: *proof-of-concept classifier trained on real bench-captured
geophone data, n=12 events, 100% on a 3-event held-out test set; not field-validated.*

## Convergence note

The first training run did **not** converge — loss sat at 0.6925 (= ln 2, the model emitting 50/50)
for all 100 epochs, with a meaningless `accuracy: 1.0000` beside it and an sklearn
`UndefinedMetricWarning: Only one class is present in y_true` from a validation split that happened
to land single-class. That was diagnosed rather than accepted: the local RMS measurement above
proved the data is perfectly separable, so the failure was numerical, not evidentiary — spectral
features of order 1e-4 give a dense network vanishing gradients. Rescaling volts to millivolts
(`scale-axes = 1000`) and retraining at lr 0.005 for 200 cycles produced a normal learning curve
(epoch 1 loss 3.97 / acc 0.43, converged by ~epoch 28).

## Reproducing

```
export EI_API_KEY=ei_...          # project 1094084 API key, not stored in this repo
export EI_PROJECT_ID=1094084
python scripts/edge_impulse_upload_seismic.py
```

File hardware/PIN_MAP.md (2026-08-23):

# EleTect X — MCU pin assignment map

Single reference table for every STM32U585 (reflex MCU) pin this project uses. Source of truth for
each row is `device/mcu/src/config.h` (assigned pins) and `hardware/references/UNO_Q_PINOUT_REFERENCE.md`
(the transcribed Arduino UNO Q pinout). D3/D8 are the two new pins from the 22 Aug 4-channel LED
redesign (`hardware/WIRING_GUIDE.md` §4.0) — confirmed free and PWM-capable, not yet added to
`config.h`. See `hardware/eletect-x-full-system.kicad_sch` for the full wiring diagram this table
matches net-for-net.

| Arduino pin | MCU pin | `config.h` name | Drives | Wiring status |
|---|---|---|---|---|
| D0 | PB7 (USART1_RX) | `LORA_UART_RX_PIN` | Grove LoRa-E5 TX → D0 | **P** — wired 18 Aug, not yet answering AT probes |
| D1 | PB6 (USART1_TX) | `LORA_UART_TX_PIN` | Grove LoRa-E5 RX ← D1 | **P** — same as D0 |
| D2 | PB3 (TIM2_CH2) | `AUDIO_TRIGGER_PIN` | DFPlayer PRO `KEY` (active-low, direct jumper) | **U** |
| D3 | PB0 (OPAMP2 out, TIM3_CH3, PWM) | *planned* `LED_WHITE_RIGHT_PIN` | IRLZ44N gate, white LED branch, right wing | **U**, not in `config.h` yet |
| D4 | PA12 (FDCAN1_TX, TIM1_ETR) | `HORN_AMP_ENABLE_PIN` | IRLZ44N gate, XH-M543 amp VCC-side enable (active-low) | **U** |
| D5 | PA11 (FDCAN1_RX, TIM1_CH4, PWM) | `LED_WHITE_PIN` → planned `LED_WHITE_LEFT_PIN` | IRLZ44N gate, white LED branch, left wing | **U** |
| D6 | PB1 (TIM3_CH4, PWM) | `LED_BLUE_PIN` → planned `LED_BLUE_LEFT_PIN` | IRLZ44N gate, blue LED branch, left wing | **U** |
| D7 | PB2 (TIM8_CH4N) | `IR_ILLUMINATOR_PIN` | IRLZ44N (or LR7843 module) gate, IR board | **U** |
| D8 | PB4 (TIM3_CH1, PWM) | *planned* `LED_BLUE_RIGHT_PIN` | IRLZ44N gate, blue LED branch, right wing | **U**, not in `config.h` yet |
| D20 | PB11 (I2C2_SDA) | `GEOPHONE_I2C_SDA_PIN` | ADS1115 SDA (geophone front-end) | **W** — confirmed wired |
| D21 | PB10 (I2C2_SCL) | `GEOPHONE_I2C_SCL_PIN` | ADS1115 SCL | **W** — confirmed wired |
| PH10/PH11/PH12 | on-board RGB LED 3 | `STATUS_LED_R/G/B_PIN` | unassigned — no pre-defined meaning | unused; pin exposure unconfirmed (KNOWN_GAPS) |

**Free/unused digital pins** (available for future use, none claimed by this design): D9 (PB8,
TIM4_CH3), D10 (PB9, SPI2 SS), D11 (PB15, SPI2 MOSI), D12 (PB14, SPI2 MISO), D13 (PB13, SPI2 SCK).
Qwiic connector I2C4 (PD12/PD13) is also free, reserved per `config.h`'s own comment for a future
BME280/MPU-6050.

**INMP441 acoustic mic is not in this table.** It lives on the MPU (QRB2210) side's own
I2S/audio path per `CONTEXT.md`'s software split, not through this MCU GPIO header — no pin
assignment for it exists in `config.h` yet. Do not infer wiring for it from this document.

## Power rails (not MCU GPIO, included for completeness)

| Net | Source | Feeds |
|---|---|---|
| `BATBUS_12V8` | Battery+ → 6A blade fuse → SPST switch → WAGO 5-way splice | UNO Q VIN, TPA3116D2 XH-M543 VCC (direct), LED buck #1 in, LED buck #2 in, IR buck #3 in |
| `RAIL_5V` | UNO Q 5V pin | DFPlayer PRO VIN, Grove LoRa-E5 VCC — explicitly *not* on the 12.8V actuator bus |
| `LEDBUS_WHITE` | XL4015 buck #1 output | White-left + white-right LED branches (parallel) |
| `LEDBUS_BLUE` | XL4015 buck #2 output | Blue-left + blue-right LED branches (parallel) |
| `IR_12V` | XL4015 buck #3 output, set ~12V | VISTORA 48-LED IR board (fixed 12V spec, no input tolerance margin) |

Full derivation, wire gauges, and connector choices: `hardware/WIRING_GUIDE.md` §1 and
`hardware/bom/procurement-status.md`.

*Generated 23 Aug 2026 alongside `hardware/eletect-x-full-system.kicad_sch` — keep both in sync with
`config.h` as the LED 4-channel firmware lands and D2/D4/D5/D6/D7 wiring status flips from U to W.*

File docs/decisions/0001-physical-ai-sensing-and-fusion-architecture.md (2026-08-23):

# ADR 0001: Physical-AI sensing, vision pipeline, and fusion architecture

- **Status:** accepted
- **Date:** 2026-07-12

## Context

CONTEXT.md §4 freezes the reflex/cognition split and the log-odds fusion formula, but left three things underspecified enough to be risky for a real field deployment: (1) which ADC the geophone front-end actually uses in the final node, (2) what model architecture and tooling the vision stage runs, and (3) whether the fusion math's assumptions (independence across modalities, missing-sensor handling) are actually sound rather than just convenient. These matter because DFO Kothamangalam has approved a real field deployment — a wrong call here isn't a contest-scoring risk, it's a missed-elephant or false-alarm risk for people who will depend on this. This ADR was preceded by two independent research passes (general-purpose agents) covering (a) vision architecture options given QRB2210's actual hardware — quad Cortex-A53, Adreno 702 GPU, **no Hexagon NPU** — and (b) real-world HEC sensor-fusion precedent and the statistical soundness of the fusion design.

## Decision

**1. Geophone ADC:** drop the ADS1115 from the final node. SM-24 → INA333 → Sallen-Key band-pass 2–50 Hz → **STM32U585 internal ADC (LPBAM)**. ADS1115 stays a bench-only stand-in for early STA/LTA prototyping before the STM32 path is validated (already reflected in CONTEXT.md §3 and PROJECT_BLUEPRINT.md §4 — no further change needed there).

**2. Seismic target band:** keep the existing 2–50 Hz band-pass as-is. Research corrected an earlier internal assumption that elephant footfall centers around ~14 Hz — published seismology (O'Connell-Rodwell et al., 2000, JASA) puts footfall/stomp at **~24 Hz mean (±3)** and rumble-vocalization seismic coupling at ~20 Hz; embedded-systems HEC papers design around a 10–80 Hz window. The existing 2–50 Hz band already covers this correctly; nothing to change in hardware or firmware, but any STA/LTA or TinyML feature-extraction tuning should target ~20–24 Hz, not 14 Hz.

**3. Vision detector: FOMO (Edge Impulse) stays primary, with an explicit mitigation and a documented fallback.** Train and deploy an Edge Impulse FOMO detector (elephant / wild boar / background classes) on the QRB2210 via Edge Impulse's Linux/AARCH64 SDK, generic CPU/TFLite path (no QNN/Hexagon delegate available on this chip). Mitigate FOMO's known weakness — it predicts one centroid per grid cell and fails on overlapping objects or one large object dominating the frame — by increasing input resolution / heat-map grid density during training, and by treating FOMO's output strictly as "elephant present, approximate location," never as a herd count or size/distance estimate. This keeps vision on the same Edge Impulse platform as seismic and acoustic (one training/deployment toolchain, one team skill, one OTA update mechanism per CONTEXT.md §4's "vision model fixed, OTA-updated centrally") and fits inside the ~6-week runway to the Robu deadline.

**4. MegaDetector's role stays offline-only, but the reason changed.** Originally justified by MDv5's 121M parameters being too heavy for a no-NPU chip. Research found MDv6-compact is only **2.3M params** and has already been deployed on solar-powered edge hardware (Microsoft's SPARROW project) — so "too heavy" is no longer the correct justification. The actual reason to stay offline-only now: adopting MDv6-compact on-device would mean a two-stage detect-then-classify pipeline on a *different* toolchain (ONNX/PyTorch-Wildlife) than the rest of the sensor stack, adding integration surface and a second model to validate/maintain under a fixed deadline, for a benefit (real bounding boxes, no overlapping-centroid failure mode) that doesn't change the actual decision this system needs to make (present/not present, not count or precise scale). MegaDetector continues to be used purely offline, as a Roboflow model-assisted labeling accelerator when building the training dataset.

**5. Documented fallback, not pursued now:** if field testing during the August DFO test shows FOMO's overlapping-centroid failure meaningfully hurts real detection reliability (e.g., missed elephants in herds or at close range), the fallback is MDv6-compact (generic detector) + a small custom crop-classifier (elephant/boar/background), which is proven deployable on comparable solar-edge hardware. This is a v2 item, not a pre-launch requirement — evaluating it now would cost timeline for a failure mode that may not materialize in practice, since presence detection (not counting) is the actual requirement.

**6. Fusion stays log-odds, with two limitations now documented instead of assumed away.** `L = L_prior + Σ aᵢwᵢ(ℓᵢ−ℓ₀ᵢ)`, `P = σ(L)` is a legitimate, standard technique — it is Bayesian log-odds updating under conditional independence, the same math used in robotics occupancy-grid fusion, and it's computationally cheaper than Dempster-Shafer while being provably equivalent to it under uninformative priors. Two assumptions it relies on are not automatically true here and should be tracked as known limitations rather than presented as solved:
   - **Conditional independence across modalities** is violated when a shared confound (rain/fog) degrades seismic SNR and vision IR contrast simultaneously — the fusion formula would overstate confidence in that scenario. No fix planned for launch; flagged for future work (e.g., a shared "environmental degradation" state feeding an explicit weight adjustment).
   - **Availability-gated dropout** (a missing modality is excluded from the sum, not scored as negative evidence) is only statistically neutral if missingness is uncorrelated with the true event (MCAR). It plausibly is not: vision can be unavailable specifically due to fog/rain, and elephant activity is plausibly not independent of those same conditions. Kept as-is for launch (dropout is the simplest, most auditable behavior, and matches CONTEXT.md §7's "simplicity over complexity"), but documented here as an approximation, not a proven property, so it doesn't get treated as settled in a later design review.

## Alternatives considered

- **YOLO-nano-class (YOLOv8n/YOLO11n) TFLite on-device instead of FOMO** — real benchmark data on Cortex-A53 + Adreno 702 (same GPU class as QRB2210) shows ~360 ms per inference via GPU delegate, which comfortably fits this system's event-triggered latency budget (hundreds of ms to ~2 s). Rejected for now because it doesn't solve a problem FOMO actually has for this use case (presence detection, not counting/bbox precision) and it fragments tooling away from the Edge Impulse platform used for seismic/acoustic. Worth a bake-off later if FOMO's field recall disappoints.
- **MDv6-compact + custom classifier on-device now, instead of at launch** — rejected for timeline/toolchain-fragmentation reasons (see decision §5), not accuracy reasons; kept as the documented v2 fallback.
- **Dempster-Shafer evidence fusion instead of log-odds** — better at representing explicit ignorance and reconciling conflicting high-confidence sensors, but higher compute cost and conceptual overhead for a bounded MCU/MPU budget, and only diverges meaningfully from Bayesian log-odds when priors are informative in ways this system doesn't need yet. Rejected; revisit only if field data shows log-odds fusion is materially miscalibrated.
- **Learned meta-classifier / stacking for fusion weights** — empirically can outperform hand-set weights, but needs a labeled multi-modal field dataset that doesn't exist yet. Rejected for launch; realistic as a v2 upgrade once field events accumulate.

## Consequences

- Vision, seismic, and acoustic all train and deploy through Edge Impulse — one toolchain, one OTA path, matches the frozen "vision model fixed, OTA-updated centrally" design.
- Known, accepted risk: FOMO may under-detect herds or very-close-range elephants due to centroid overlap. Mitigated by resolution tuning and by not depending on count/size from vision alone; monitored explicitly during the August field test.
- Realistic accuracy expectations, to set correctly in DFO conversations and in contest documentation rather than overselling: seismic-alone field accuracy in natural/HEC habitat (not lab/zoo conditions) should be expected around **70–75%**, not the ~99% lab figure that sometimes gets quoted; vision-alone precision/recall at launch, given a contest-timeline dataset (likely 500–1,000+ images per class per lighting condition is the real target, not achievable in full for night conditions before the August field test), should be expected around **70–85%**. This is the actual quantitative case for why fusion — not any single modality — carries the reliability requirement, and it should inform alert-escalation and human-in-the-loop fallback thresholds, not just be a footnote.
- No published field precedent exists for a fused seismic+acoustic+vision elephant detector specifically — this project's fusion layer is genuinely novel, not a replication of a proven design. State this honestly in contest documentation rather than implying more precedent than exists.
- Two fusion-math limitations (correlated-noise confound, MCAR assumption in dropout) are now written down as known, accepted approximations rather than silently assumed — future work items, not blockers.

## Physical AI framing (addendum, not a separate decision)

Qualcomm's own "Brain + Nervous System" robotics reference architecture — the same vendor as QRB2210 — maps directly onto this project's reflex (STM32, always-on, real-time trigger) / cognition (QRB2210, event-driven perception+decision) split, which is a strong, specific precedent for calling this design "Physical AI" rather than just "embedded ML." Where the design is *not* the full closed-loop ideal some Physical AI literature describes: deterrence action itself (horn/LED trigger) is open-loop in the sense that it doesn't yet measure whether the elephant actually retreated and feed that back into perception thresholds. It's worth noting, though, that the frozen design already has real closed-loop adaptation on the *decision* side — the contextual bandit (CONTEXT.md §4: "never-repeat, stop-on-retreat," SQLite experience) already learns from deterrence outcomes and adapts action selection over time. So the honest scoping is: perception (fusion weights, thresholds) is fixed/centrally-updated, not self-adapting in the field; action selection (which deterrence to use, when to stop) already is. Contest and DFO documentation should describe it this way rather than either overclaiming full closed-loop autonomy or underselling the bandit's existing adaptation.

## Addendum, 29 Jul 2026 — geophone damping resistor

Decision #1 fixed the SM-24 → INA333 → Sallen-Key → STM32 ADC chain but left the geophone's own
electrical damping unaddressed. The SM-24's manufacturer datasheet (I/O Sensor Nederland, part
1004117) specifies open-circuit damping of only **h=0.25** at its 10 Hz natural frequency — badly
underdamped, meaning an unshunted coil rings for several cycles after any impulsive input rather
than producing a clean transient. Left unaddressed, this would corrupt the STA/LTA envelope shape
the footfall trigger depends on before any firmware or ML logic sees the signal.

**Decision:** wire a 1 kΩ shunt resistor directly across the SM-24's own two leads, upstream of the
burial cable, targeting h≈0.7 (the standard maximally-flat/minimal-overshoot damping target for
resolving a transient, as opposed to the flatter-passband target exploration seismology typically
uses). Derivation, using the datasheet's own transduction constant and its own worked example as a
check:

`R_shunt = RtBcfn / (fn × (h_target − h_open)) − Rc`

Datasheet values: `RtBcfn = 6,000 Ω·Hz`, `fn = 10 Hz`, `Rc = 375 Ω` (coil resistance),
`h_open = 0.25`. Formula check against the datasheet's own published calibration point
(1,339 Ω shunt → h=0.60): `6000/(10×0.35) − 375 = 1339.3 Ω` ✓. At the chosen `R_shunt = 1 kΩ`:
`h = 0.25 + 6000/(10×1375) = 0.686`, i.e. h≈0.69 — matching one of the two damping curves plotted
directly on the datasheet's own frequency-response and phase-lag graphs, not an extrapolation.
1 kΩ was chosen over the theoretically closer ~958 Ω because it is a standard value already in the
existing resistor kit (`hardware/bom/procurement-status.md`), and resistor tolerance is not
critical to this calculation — no new procurement needed.

**Placement matters:** the shunt must sit at the geophone end, not the amplifier end, so cable
resistance from the burial run doesn't add into the effective coil resistance and shift the
delivered damping away from this calculation. Reflected in `device/mcu/README.md`'s wiring table.

**Mechanical note, not electrical, but from the same datasheet:** all SM-24 parameters are
specified "in the vertical position," with a maximum 10° tilt for the rated 10 Hz Fn. Worth
carrying into the burial spike/pipe mounting geometry in `hardware/bom/procurement-status.md` §3,
not just the electrical design here.

**Deferred, not decided:** a small clamp/TVS across the differential pair for lightning/ESD
protection on the long buried cable run. Worth a field-hardening pass before the DFO deployment,
not a Rung 1 bench-test blocker — logged in `docs/KNOWN_GAPS.md`.

## Addendum, 30 Jul 2026 — INA333 input series resistors

A third-party SM-24+ADS1115 build (Core Electronics' Raspberry Pi geophone guide) wires two 1 kΩ
resistors in series between the sensor and the ADC's differential inputs, purely for ESD/transient
current-limiting — separate from that design's own damping resistor. Their topology has no
instrumentation amp, so the ADC is the first thing the buried-cable signal touches; ours interposes
the INA333, so the equivalent boundary in our chain is the INA333's own `IN+`/`IN-` pins, not the
ADS1115's `AIN0`/`AIN1` (which already sit downstream of the amp, inside the enclosure).

**Decision:** add a 1 kΩ resistor in series with each of the INA333's `IN+` and `IN-` leads,
between the damping-resistor node and the amp's inputs. Negligible effect on the signal — the
INA333's input impedance is high enough (typical CMOS instrumentation-amp input stage) that a 1 kΩ
series resistor forms an RC corner with parasitic input capacitance many orders of magnitude above
the 2–50 Hz seismic band — while giving the amp's internal input-ESD structures some current
limiting against a transient coupled onto the buried cable. Same 1 kΩ value as the damping
resistor and already in the kit; no new procurement.

**This is not a substitute for the deferred TVS/clamp above.** A resistor limits steady current; it
does not clamp voltage or absorb real transient energy the way a TVS diode or gas-discharge tube
would. A genuine lightning-induced surge on a long buried run could still exceed both the resistor's
rating and the INA333 input stage's clamp current despite this addition. Treat this as free, partial
insurance layered under the still-open TVS/clamp item, not a resolution of it — that gap stays open
in `docs/KNOWN_GAPS.md`.

Reflected in `device/mcu/README.md`'s wiring table.

## Evidence / sources

- O'Connell-Rodwell et al., "Seismic properties of Asian elephant vocalizations and locomotion" (JASA, 2000) — https://pubs.aip.org/asa/jasa/article/108/6/3066/554703/
- "Towards Long Range Detection of Elephants Using Seismic Signals" — https://arxiv.org/pdf/2406.05140
- "Event Detection and Classification for Long Range Sensing of Elephants Using Seismic Signals" — https://arxiv.org/pdf/2509.02920
- Edge Impulse, FOMO docs and limitations — https://docs.edgeimpulse.com/docs/edge-impulse-studio/learning-blocks/object-detection/fomo-object-detection-for-constrained-devices
- ultralytics/yolov5 issue #11487 (Cortex-A53 + Adreno 702 real latency numbers) — https://github.com/ultralytics/yolov5/issues/11487
- MegaDetector v5 vs v6 parameter counts and SPARROW edge deployment — https://www.animaldetect.com/blog/megadetector-v5-vs-v6 , https://zenodo.org/records/20348979
- Bayesian log-odds vs Dempster-Shafer equivalence/divergence — https://arxiv.org/pdf/2602.18872
- West Bengal AI-filtered camera-alert HEC deployment (field outcome data) — https://conbio.onlinelibrary.wiley.com/doi/abs/10.1111/csp2.70186
- Qualcomm "Brain + Nervous System" robotics/Physical-AI architecture — https://www.businesswire.com/news/home/20260104991116/en/
- I/O Sensor Nederland, SM-24 Geophone Element datasheet (P/N 1004117), damping/RtBcfn/coil
  resistance specifications — manufacturer PDF, 2006
- olewolf/geophone (Arduino SM-24 amplifier shield + frequency analyzer reference) —
  https://github.com/olewolf/geophone
- Core Electronics, "Set Up a Geophone with a Raspberry Pi and an ADC (ADS1115)" — SM-24+ADS1115
  reference build, source of the input series-resistor idea and independent 1 kΩ corroboration —
  https://core-electronics.com.au/guides/geophone-raspberry-pi/

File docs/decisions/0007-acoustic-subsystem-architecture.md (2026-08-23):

# ADR 0007: Acoustic subsystem architecture — sensing, MCU/MPU split, and Edge Impulse classification

- **Status:** proposed
- **Date:** 2026-07-28

## Note (added after ADR 0009, not a rewrite of this ADR)

ADR 0009 supersedes ADR 0006's comparator-gate capture mechanism with a continuous on-MCU LPBAM classifier
as the primary design (ADR 0006 remains the documented fallback). Everything below — the per-class
signature/range table, the MCU/MPU wake sequence, the power budget, and the fusion-vs-direct-alert routing
split in Decision §5 — is unaffected and stands as written; only the "Detection tier" column's assumption
that a comparator gate is the mechanism should be read as "whichever capture mechanism ADR 0009 resolves to."

## Addendum, 30 Jul 2026 — acoustic subsystem sequenced after the DFO field test

Everything below this line still stands unchanged. This addendum records a scheduling decision,
not an architecture change: acoustic hardware bring-up, dataset collection, and Edge Impulse model
training are deferred until after the ~9-14 Aug DFO field test, freed time going instead to vision
and seismic model work and camera/video capture setup ahead of the Aug 8 freeze.

This is a safe deferral, not a scope cut, for reasons already written into this ADR and ADR 0001:
acoustic corroboration was scoped as a "stretch" from the start (`BUILD_BLUEPRINT_AUG8.md` §1), and
of its two outputs, gunshot classification was already decided (Decision §5, above) to route to its
own direct anti-poaching alert, entirely outside the elephant-presence fusion sum — so it was never
part of the loop the field test needs to prove. The other three classes (chainsaw, vehicle, animal
call) *do* feed fusion, but ADR 0001's addendum already establishes that a missing modality is
excluded from the sum, not scored as negative evidence — the system is explicitly designed to
degrade gracefully with acoustic absent, not break.

**Hardware plan:** the field-bound UNO Q keeps running seismic + vision only through the field test.
The second unit (`hardware/bom/procurement-status.md`'s permanent bench/dev board) becomes the
dedicated acoustic development unit once freed up, so acoustic bring-up never touches the
already-validated field node.

**What's already done and doesn't need redoing:** the Bridge contract (`report_acoustic_event` in
`device/mpu/bridge/schema.md` and its stub in `device/mpu/bridge/rpc.py`) and this ADR's full
architecture already exist — the acoustic subsystem is designed and its function boundary is fixed,
only its hardware bring-up and trained model are deferred. Nothing needs to be un-built or removed.

**What's actually deferred:** INMP441 hardware integration, the ADR 0009 Rung 2 LPBAM dual-channel
concurrency bench test, gunshot/chainsaw dataset collection (`DEVICE_DEVELOPMENT_WORKFLOW.md` §4a),
and Edge Impulse acoustic model training. Targeted for the post-field-test window (15-30 Aug),
alongside the Robu/Hackster submission sprints.

## Context

ADR 0006 solved one piece of the acoustic subsystem (the gunshot wake-gate and its cold-start risk) in isolation. That left the full picture scattered across several conversations: what INMP441 can actually hear and how far, how each of CONTEXT.md §3's four target classes (gunshot, chainsaw/logging, illegal vehicle entry, animal sounds) differs physically and therefore needs a different detection treatment, where each processing stage actually lives (STM32 vs QRB2210), and how Edge Impulse fits given ADR 0001's "one toolchain" principle. This ADR is the single, unified reference for all of that — it does not re-decide anything ADR 0006 already settled (the gunshot gate and its pre-trigger-buffer fix stand as written), it assembles the surrounding architecture ADR 0006 depends on and was written without.

Two pieces of hardware-level science ground everything below. INMP441's own datasheet (TDK InvenSense): sensitivity −26dBFS at 94dB SPL/1kHz, SNR 61dBA, self-noise (EIN) 33dBA SPL, dynamic range 87dB, flat frequency response 60Hz–15kHz (−3dB point at 60Hz), 1.4mA active current at 1.8–3.3V. The 60Hz low-frequency rolloff is exactly why CONTEXT.md already assigns infrasound (elephant rumble, <60Hz) to the geophone and not INMP441 — that's a hardware limit, not a design choice, and this ADR doesn't touch it.

Real-world detection range is not something to assume — it was checked against two independent field precedents rather than derived from a datasheet in isolation. A published field study ("Deploying Acoustic Detection Algorithms on Low-Cost, Open-Source Acoustic Sensors for Environmental Monitoring," PMC6387379) fired gunshots at ranges up to 800m through dense broadleaf rainforest and had a low-cost acoustic sensor and detection algorithm respond correctly — a directly comparable environment to Kerala's forest-boundary terrain. The same paper is honest about the failure mode that matters here: nearby loud fauna (the paper's example is howler monkeys, but wind, rain, and insects apply equally) can mask or overpower a gunshot occurring far away — range is a best case, not a guarantee, and the classifier has to be trained against local ambient noise, not just clean recordings. Separately, Rainforest Connection's Guardian 3 — a real, deployed, solar-powered forest bioacoustic system already covering 750,000+ hectares — detects chainsaws, vehicle engines, hunting dogs, and gunshots from a 50m–1,500m radius depending on the specific source (louder, more impulsive sources like gunshots reach the far end of that range; quieter, more localized sources the near end), and reports 96% chainsaw-detection accuracy with up to five days of advance warning before logging starts. This is strong, independent validation that the general approach — solar-powered node, mic array, ML classification of exactly these classes — is not speculative; it's a proven category of system, not a novel one.

## Decision

### Per-class signature, sensing strategy, and range

| Class | Signature | Duration | Detection tier | Realistic range (grounded above) |
|---|---|---|---|---|
| Gunshot | Broadband impulsive transient, sharp attack, decaying tail | 2–7ms primary pulse + reverberant tail | Dedicated always-on analog comparator gate (ADR 0006) → INMP441 burst capture → classify | Up to ~800m demonstrated in comparable rainforest terrain (PMC6387379); RFCx's high end (1,500m) is the ceiling for a loud impulsive source, not a floor |
| Chainsaw / tree-cutting | Sustained quasi-periodic engine+blade buzz, ~100–300Hz fundamental + harmonics, seconds to minutes | Seconds+ | Geophone/periodic-wake-gated rolling-window capture → classify (ADR 0006 stage 1) | RFCx precedent: reliable well within their 50–1,500m band; sustained lower-frequency sources propagate through canopy better than a single transient, so this is comfortably inside gunshot's range, not a stretch beyond it |
| Illegal vehicle entry | Engine/tire rumble, RPM-linked harmonics, rising-then-falling amplitude as it passes | Seconds to tens of seconds | Same rolling-window path as chainsaw; corroborated by geophone (vehicles couple to the ground far more reliably at close range than gunfire does, unlike the gunshot-geophone question ADR 0006 left open) | Deployment already limits this: CONTEXT.md §6 places GUARD-tier nodes at crossings specifically, so the sensor only needs to reliably cover a road/track width plus margin — tens of meters, not hundreds. Range is not the binding constraint for this class. |
| Animal sounds (non-infrasonic) | Species-specific vocalizations, in-band above 60Hz | Variable | Same rolling-window path, different trained classes | Elephant rumble stays out of scope for INMP441 (below its 60Hz rolloff, per datasheet) — geophone's job, unchanged from CONTEXT.md. In-band calls (trumpets, other species) follow the same range logic as chainsaw. |

The shared conclusion: one microphone, one capture path, one Edge Impulse toolchain, four trained classes — not four different sensing schemes. This directly extends ADR 0001's "vision, seismic, and acoustic all train and deploy through Edge Impulse — one toolchain, one OTA path" to the acoustic side specifically, and matches what Forest Guard's own public writeup says about its (much simpler) system: retraining the same pipeline on new classes, not rebuilding hardware, is what makes this scale to new threats later.

### MCU/MPU split — who sleeps, who runs, in order

1. **Default state (>99% of the time).** STM32 reflex layer is in its normal µA-range STOP-mode-cycling pattern, running geophone STA/LTA sampling on its own existing duty cycle. The dedicated gunshot comparator (ADR 0006 §2) runs continuously in parallel — LM393's typical quiescent current is 0.4mA for both channels combined (only one channel is used here), a small, precisely bounded addition to the existing reflex-layer budget, not a new order-of-magnitude cost. INMP441/SAI sits clock-gated (or lightly circular-buffering, if ADR 0006's §2a.1 fix is validated on the bench) — no continuous digital audio pipeline running. **The QRB2210 MPU is fully suspended, not booted** — this is the expensive component power-wise, and CONTEXT.md's "cognition (QRB2210, event-only)" already establishes it doesn't run continuously; this ADR doesn't change that, it just confirms the acoustic subsystem doesn't either.

2. **Trigger fires** — any of: geophone STA/LTA crossing threshold, a periodic maintenance wake, or the gunshot comparator. STM32 wakes fully. For the gunshot path, if the pre-trigger buffer fix is in place, audio from just before the trigger is already available; for geophone/periodic triggers, INMP441/SAI cold-starts (acceptable here since chainsaw/vehicle/call events last seconds, so a few ms of cold-start latency is irrelevant — this is exactly why ADR 0006 treats gunshot as the special case, not the general one). STM32 extracts scalar features (RMS, crest factor, spectral centroid/flatness, zero-crossing rate) and, for gunshot specifically, does a first cheap impulsive-shape check itself before deciding whether to escalate.

3. **STM32 wakes the QRB2210.** The physical mechanism for this handoff isn't yet pinned down anywhere in CONTEXT.md or the existing ADRs — flagged here as an open item this ADR surfaces rather than resolves, since it affects every event-driven wake in the system, not just acoustic ones.

4. **QRB2210 awake, cognition layer active.** Boots/resumes, pulls the captured audio (features or raw window) from STM32 over Bridge/SPI, and classifies it. Important precision here: we are **not** using Arduino's stock `audio_classification` Brick's built-in input loop (it expects a USB mic on the Linux side, continuously listening — incompatible with this whole power argument, per ADR 0006). We **are** still using the same underlying Edge Impulse deployment artifact and Python runtime the Brick wraps — a model trained in Edge Impulse Studio, exported for the UNO Q/Linux aarch64 target, invoked directly against our own captured buffer instead of a live mic stream. Same toolchain, same `.eim`/SDK mechanics, custom input plumbing — consistent with how the vision model already works per ADR 0001, and with what the Brick's own `classify_from_file()` call does structurally.

5. **Result routing — this is a real distinction this ADR adds, not previously stated anywhere.** Not every acoustic classification result should feed CONTEXT.md §4's log-odds fusion formula. That formula (`L = L_prior + Σ aᵢwᵢ(ℓᵢ−ℓ₀ᵢ)`, `P = σ(L)`) is scoped around one question: is an elephant present. Chainsaw, vehicle, and animal-call classifications are legitimate evidence toward that question and should feed the fusion sum as weighted log-odds terms, same as vision and geophone. **Gunshot is not evidence toward "is an elephant present" — it's a categorically different alert (anti-poaching, human safety), and folding it into the elephant-presence fusion score would be a modeling error, not just an oversimplification.** A gunshot classification should trigger its own direct alert path (LoRa to forest officers) independent of the bandit/deterrence decision entirely — you don't deter a gunshot with LEDs and a horn, you alert rangers. This routing split needs to be reflected wherever the fusion/alert logic actually gets implemented; it isn't yet.

6. **MPU returns to suspend, STM32 returns to reflex-only sleep.** The comparator and geophone remain the only continuously-active elements, closing the loop back to state 1.

### Power budget

- Geophone STA/LTA: unchanged, already inside the existing always-on budget (ADR 0001).
- Gunshot comparator: +0.4mA typical (LM393, both channels; only one used) — small and precisely bounded, not a guess.
- INMP441: 1.4mA active current, but only during event windows (seconds), never continuous under this design — negligible contribution to the multi-day average regardless of which classifier class triggered the capture.
- QRB2210: the dominant power draw whenever it's awake, but this is an existing, already-accepted cost of the event-only cognition tier (ADR 0001) — the acoustic subsystem adds one more class of *trigger* for an MPU wake (alongside geophone and periodic wakes already planned), it does not add a new *always-on* MPU cost.

### Scalability

Because all four classes share one capture path and one Edge Impulse project, adding a new acoustic threat class later (a new poaching method, a new vehicle type, a new species call) is a retraining and redeployment exercise — new labeled data, retrain, redeploy the `.eim` to the QRB2210 — not a hardware or firmware redesign. This is the same OTA-updateable, single-toolchain property ADR 0001 already established for vision.

## Alternatives considered

- **Separate detection hardware/pipeline per class** (e.g. a dedicated chainsaw sensor, a dedicated vehicle sensor). Rejected — contradicts CONTEXT.md §7's "reject gimmicks" / "simplicity over complexity," and there is no physical reason to: all four classes are audible to the same microphone in the same frequency band (except elephant infrasound, already the geophone's job), so multiplying hardware would only multiply cost and failure modes without improving detection.
- **Route all acoustic classifications through the elephant-presence fusion formula uniformly.** Rejected in Decision §5 above — gunshot specifically is not elephant-presence evidence, and treating it as such would both weaken the fusion score's meaning and slow down what should be a direct, urgent alert.
- **Use Arduino's stock `audio_classification` Brick as-is.** Rejected per ADR 0006 — its continuous-MPU-listening assumption is incompatible with the power architecture.

## Consequences

- This ADR does not change ADR 0006's gunshot-gate design or its open bench-validation items — it sits alongside it as the full-system view.
- New open item this ADR surfaces: **the STM32→QRB2210 wake mechanism itself isn't specified anywhere yet.** This affects every event-driven wake (geophone, gunshot, periodic), not just acoustic, and should probably be its own ADR rather than settled as a side effect of this one.
- New open item: the fusion-vs-direct-alert routing split (Decision §5) needs to be reflected in whatever module actually implements fusion/alerting — currently undocumented outside this ADR.
- Range figures here (800m gunshot, 50–1,500m RFCx band) are strong field precedent, not a guarantee for this specific site — Kerala's canopy density, terrain, and node placement will all shift real numbers, and the PMC study's own caveat (nearby loud fauna can mask a distant gunshot) applies directly. Treat these as "this class of system is proven to work at these orders of magnitude," not as a committed spec.

## Evidence / sources

- INMP441 datasheet (TDK InvenSense) — sensitivity, SNR, self-noise, frequency response, current draw — https://www.digikey.com/htmldatasheets/production/1431884/0/0/1/inmp441-datasheet.html
- "Deploying Acoustic Detection Algorithms on Low-Cost, Open-Source Acoustic Sensors for Environmental Monitoring" (gunshot detection to 800m in dense rainforest) — https://pmc.ncbi.nlm.nih.gov/articles/PMC6387379/
- Rainforest Connection Guardian 3 — real deployed forest bioacoustic system, 50–1,500m detection radius, 96% chainsaw accuracy, 5-day advance warning — https://rfcx.org/guardian
- LM393 datasheet — 0.4mA typical quiescent current — https://www.onsemi.com/download/data-sheet/pdf/lm393-d.pdf
- ADR 0001 (fusion formula, one-toolchain principle); ADR 0006 (gunshot gate, mic capture feasibility, App Lab Brick incompatibility); CONTEXT.md §3/§4/§6

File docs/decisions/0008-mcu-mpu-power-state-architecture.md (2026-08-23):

# ADR 0008: MCU/MPU wake, sleep, and power-state architecture

- **Status:** proposed — decision reached (deep suspend, not full poweroff); two confirming bench measurements remain before this can move to accepted
- **Date:** 2026-07-28

## Context

ADR 0007's Consequences section flagged an open item: "the STM32→QRB2210 wake mechanism itself isn't specified anywhere yet." Chasing that down surfaced a problem bigger than the acoustic subsystem — it calls into question whether CONTEXT.md §4's reflex (STM32, always-on µA) / cognition (QRB2210, event-only) split behaves the way the rest of the architecture assumes, on this specific board.

Three independent, credible sources, all real measurements rather than assumptions:

1. **Boot time.** A community benchmark using a logic analyzer measured **43.06s from power-on to the first sketch instruction on the MCU, and 46.37s to the first MPU-driven LED state change** ([myembeddedstuff.com](https://myembeddedstuff.com/arduino-uno-q-boot-time), cross-posted to the [Arduino forum](https://forum.arduino.cc/t/arduino-uno-q-the-43-second-boot-time-a-technical-breakdown-using-a-logic-analyzer/1425354)). By default the MCU sketch doesn't even start running until Linux/the App has booted — there is a "Startup mode" board option (`wait_linux_boot`: `yes` / `no` / `app`) where `no` ("Immediate") lets the sketch run at power-on regardless of Linux state, which is the mode this project needs, not the App Lab default.

2. **Standby power.** A separate forum user built almost exactly our use case — "the device needs to monitor a sensor continuously, such as a microphone... wake the MPU only when a relevant event is detected" — and measured real current draw with a lab supply: **deep suspend ≈0.082–0.088A @5.1V (≈0.42–0.45W); poweroff/shutdown ≈0.028A @5.1V (≈0.14W), with the MCU/LED matrix still visibly active in that state** ([forum thread](https://forum.arduino.cc/t/uno-q-edge-ai-is-promising-but-low-power-standby-is-difficult-for-always-on-sensing-applications/1446170)). Their own calculation: even the best of these states gives **3–5 days of standby** on a battery-only 18650/12V-SLA-class supply — nowhere near the multi-week autonomy an always-on field sensor needs. This is the single most important number to react to: it's roughly two to three orders of magnitude above a true µA-class reflex-only budget.

3. **Reset coupling.** A third thread ([link](https://forum.arduino.cc/t/can-the-stm32u585-mcu-keep-running-uninterrupted-while-the-qrb2210-mpu-reboots-or-enters-sleep-on-arduino-uno-q/1447600)) confirms the MCU **is reset when the MPU reboots** ("Yes," from an Arduino forum regular who tested it directly). Whether *suspend* (as opposed to reboot/shutdown) also resets the MCU is unconfirmed either way in that thread. Separately, in the low-power-standby thread above, a different user (`zarzi`) describes wanting exactly this project's split — STM32 hosts always-on sensing/wake logic, QRB2210 powers down completely between events — and concludes it isn't achievable today: *"all of this would require the ability to power down the MPU completely... "* with no confirmed mechanism for the MCU to bring it back up.

Put together: this board was not demonstrably designed, as shipped, for "MCU always awake at µA, MPU fully off until an external event wakes it cheaply and quickly." That's a real gap between what CONTEXT.md §4 assumes and what's been independently measured and reported by other builders on the same hardware. This is not a reason to panic or to abandon the reflex/cognition split — it's a reason to size the power budget around real numbers and pick a concrete power-state strategy deliberately, rather than let the assumption stand unexamined into the field-test build.

## Decision

**Default architecture: keep the MPU in deep suspend (Option A), not full poweroff, between events.** This is a real decision, not a placeholder, reached by re-verifying the one number that actually resolves the A-vs-B tradeoff: how much warning time the geophone genuinely buys us before an elephant reaches the boundary.

The field-*validated* (not theoretical) geophone detection range for elephant footfall is **140m in natural environments, 155.6m in controlled conditions, at 99.5% accuracy** (Wijayakulasooriya et al., cited fully below — this is the same paper family ADR 0001 already draws on for the seismic band, re-checked here specifically for range rather than frequency). The paper also cites much larger theoretical/instrumental limits (rumbles above ambient noise to 16km, stomps to 32km) — those are not the number to design a wake-latency budget against; they describe what a sensitive seismometer can detect in principle, not what a low-cost embedded geophone-and-amp chain reliably triggers a STA/LTA threshold on in the field. 140–155m is the honest number.

At a normal elephant walking pace (roughly 1.1–1.7 m/s), that range gives **~80–140 seconds of lead time** between geophone trigger and boundary arrival — comfortably more than a ~43–46s MPU cold boot plus whatever inference/fusion/decision time follows. But at a faster, agitated pace (an elephant that's already alarmed or moving with purpose can cover ground at 2.5–3+ m/s), the same range gives only **~45–65 seconds** — thin enough that a full cold boot alone could consume most or all of the available warning, before vision inference, fusion, and the bandit's decision even start. That worst case is exactly the scenario where a fast response matters most, so "usually fine" isn't good enough here.

Combined with the second open finding from Context — **no confirmed mechanism exists for the MCU to reliably power the MPU back up from a full poweroff state** (the Arduino community's own consensus, not just this project's assumption) — Option B (full poweroff) is rejected outright, not just deprioritized: it's both the riskier latency profile *and* the one nobody has shown how to implement on this board without additional hardware (an external MOSFET gating the MPU's rail, itself unconfirmed as physically accessible without a board modification). Option C (hybrid, gated by activity timing) is shelved for the same reason it was flagged as incomplete in the first draft of this ADR: it needs site-specific elephant activity data (e.g. dusk/night crossing patterns) this project doesn't have yet, and isn't worth the added firmware complexity until that data exists — it remains a plausible v2 refinement, not a launch requirement.

**So: MPU stays in deep suspend continuously (not powered fully off), and its ~0.42–0.45W continuous draw (≈10.8Wh/day) is now an explicit, named line item in the power budget rather than an unexamined assumption.** Against a 20W solar panel, that's a real but not obviously fatal fraction on a good day; it becomes the binding constraint specifically during Kerala's monsoon season, when solar harvest drops well below the annual average — which is the case worth stress-testing the budget against, not the average case.

Two specific confirming measurements remain — narrowed down from the original open-ended bench-validation ask to exactly what this decision depends on:

1. **Suspend-to-resume latency on our own board** (distinct from the 43–46s cold-*boot* figure, which is a different transition). Real Linux ARM platforms typically resume from suspend in low single-digit seconds, well inside even the 45–65s worst-case window, but this hasn't been measured on this specific board/OS image and needs to be before this decision is fully closed out.
2. **Monsoon-season solar budget recomputation**, folding in the newly-quantified 10.8Wh/day MPU-suspend baseline against realistic (not annual-average) irradiance for the wettest months, since that's the actual stress case this decision needs to survive.

## Alternatives considered

- **B. Full MPU poweroff between events, cold-boot on trigger.** Rejected — see Decision above: no confirmed wake-back-up mechanism, and even if there were one, the ~45–65s worst-case elephant lead time leaves too little margin against a ~43–46s cold boot plus inference/fusion/decision time on top, precisely in the fast-moving-animal case where margin matters most.
- **C. Hybrid, gated by time-of-day/activity probability.** Shelved, not rejected — needs site-specific activity data this project doesn't have yet; worth revisiting as a v2 power optimization once field data exists, not a precondition for the initial build.

## Consequences

- **This affects every subsystem that depends on an MPU wake, not just acoustic** — vision/fusion, the contextual bandit, LoRa uplink of decisions. ADR 0007's acoustic-specific wake question is resolved by this decision too: gunshot/chainsaw/vehicle/animal-call classification all wake an already-suspended (not powered-off) MPU, same as the geophone path.
- CONTEXT.md §4 and §3's power-system BOM (4S LiFePO4 + MPPT + 20W solar) were sized without the ~10.8Wh/day MPU-suspend baseline. Recommend this gets folded into a real monsoon-season-specific budget recomputation rather than checked only against the annual-average solar assumption implicit in the current BOM.
- Reflex-layer safety net worth considering separately (not decided here, flagged for its own discussion): since even deep suspend has some resume latency, a simple STM32-only fallback deterrence trigger (basic horn/LED burst, no vision confirmation) for the rare case of an unambiguously strong, close geophone signal would remove dependence on MPU wake timing entirely for the worst-case scenario. This would be a genuine addition to CONTEXT.md §4's reflex-layer duties, not something already covered by "actuator timing; safety rule-gates" — worth its own decision, not smuggled in here.
- Two confirming measurements before this ADR can move to accepted:
  1. Suspend-to-resume latency on our own board (flash a minimal "Immediate" startup-mode sketch, command suspend, measure wake time — needs no new parts, just the board and a multimeter/scope already in hand).
  2. Power budget recomputation against realistic Kerala monsoon-season solar irradiance, not annual average, with the 10.8Wh/day MPU baseline included explicitly.
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

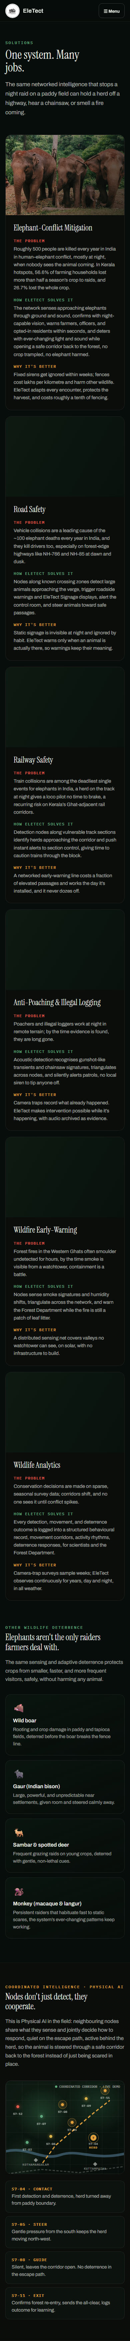
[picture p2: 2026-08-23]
docs/qa/phase2/solutions-design-mobile.png

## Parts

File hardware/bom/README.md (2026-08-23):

# Bill of Materials

Single home for the BOM (node + pods). See bom.md.

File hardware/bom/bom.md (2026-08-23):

# EleTect X — FINAL Hardware Sourcing (Freeze & Build) — Complete BOM

**All parts India-available (Amazon.in / Robu / local); no imports.** Legend: ✅ HAVE · 🛒 BUY · ⭐ decision note. Prices ≈ July 2026, confirm at cart.

---

## 0. Two decisions locked
- **Camera — LOCKED: `B0CQ4QDCXN` = Arducam IMX462 day/night, auto IR-cut + 940 nm IR, ₹8,680 (Amazon.in).** Only one of the three available that is a proper **active-IR** day/night camera with a top NIR sensor → correct for dark forest. ⚠️ NOT `B0829HZ3Q7` (₹5,932 = OV2710, weak night — budget fallback only, 850 nm). ⚠️ NOT Robu `B0576` IMX662 (₹6,699) — it's a low-light *color* cam with no IR-cut/IR LEDs listed → likely can't do active-IR night; skip unless Robu confirms NoIR. **External IR = 940 nm to match.**
- **Speaker — LOCKED per ADR 0003/0005: Ahuja SUH-15**, flush-mounted into the front face, ₹1,299–3,150. A TOA SC-610 detour (ADR 0004) was reverted (ADR 0005) — it solved the enclosure's "generic box" look with a 3–6x costlier part instead of a form-language fix, which contradicts the project's own cost-effectiveness/scalability principle and meaningfully raises real fleet cost at DFO deployment scale. Compactness/aesthetics are addressed in the enclosure design instead (sentinel two-volume form, visor band, tapered horn cutout).

---

## 1. Compute, comms, core (mostly HAVE)
| Item | Spec | Qty | Status | Source / ₹ |
|---|---|---|---|---|
| Arduino UNO Q | 2 GB | 1 | ✅ HAVE | — |
| LoRa radio | Grove LoRa-E5 (IN865) | 1 | ✅ HAVE | — |
| Amplifier | TPA3116D2 board | 1 | ✅ HAVE | — |
| Mic | INMP441 (I²S) | 1 | ✅ HAVE | — |
| Instrumentation amp | INA333 (module) | 1 | ✅ HAVE ("mic ina") — *confirm it's INA333* | — |
| Geophone | SM-24 10 Hz | 1 | ✅ arriving | — |
| USB hub | — | 1 | ✅ HAVE — **not needed** in frozen design (camera on USB-C direct, audio via DFPlayer). Keep as spare. | — |

---

## 2. Camera + IR subsystem 🛒
| Item | Spec | Qty | ₹ | Source |
|---|---|---|---|---|
| **USB camera** | Arducam **IMX462** day/night USB board — **ASIN B0CQ4QDCXN** (NOT B0829HZ3Q7=OV2710) | 1 (+1 spare rec.) | 6,000–8,680 | Amazon.in (search ASIN **B0CQ4QDCXN**) / Robu / metal-case B0490 |
| **940 nm IR illuminator** | 12 V board, ~45–60° beam, built-in driver (match camera's 940 nm) | 1 | 500–900 | Amazon.in "940nm IR illuminator board 12V" |
| IR-gate MOSFET | Logic-level N-MOSFET (AO3400 or IRLZ44N) module | 1 | 80 | Robu/Amazon.in |
| Optical window | Clear cast acrylic / PC 2–3 mm (cut to size) | 1 | 100–200 | local / Amazon.in |

---

## 3. Geophone burial chain 🛒 (see also passives §7)
| Item | Spec | Qty | ₹ | Source |
|---|---|---|---|---|
| Shielded cable | 2-core shielded (Polycab/Amazon) ~5 m | 1 | 150–400 | [Amazon.in](https://www.amazon.in/Shielded-Signal-transmission-protection-Length/dp/B07DWVY8FT) |
| Capsule | PVC pipe 32 mm + 2 end caps | 1 | 80–150 | local hardware |
| Spike | SS-304 bolt M10 × 100 mm | 1 | 80–150 | Amazon.in / hardware |
| Potting | Araldite Standard (resin+hardener) | 1 | 120–300 | [Amazon.in](https://www.amazon.in/Araldite-Standard-Epoxy-Adhesive-90gm/dp/B08FHBFY27) |
| Conduit | HDPE flexible 20 mm ~3 m | 1 | 100–200 | local / Amazon.in |
| Connector | M12 4-pin IP68 (panel + cable) | 1 | 300–600 | Amazon.in / Zbotic |
| Band-pass op-amp | MCP6002 (dual, low-power) | 1 | 40–90 | Robu/Amazon.in |

---

## 4. Audio deterrence 🛒
| Item | Spec | Qty | ₹ | Source |
|---|---|---|---|---|
| **Audio player** | **DFPlayer PRO** (onboard flash, no SD) | 1 | 500–700 | Robu/Amazon.in *(fallback: DFPlayer Mini + 8 GB microSD)* |
| Horn speaker | **Ahuja SUH-15**, 8 Ω, 15W RMS/23W Max, flush-mounted per ADR 0003 (ADR 0004 TOA SC-610 detour reverted, ADR 0005) | 1 | 1,299–3,150 | Moglix/Amazon.in, or Electrosolutions Trading LLP (Kondotty) |
| Speaker wire | 2-core, ~1 m | 1 | 30 | local |

---

## 5. Visual deterrence 🛒 (India-generic parts; see passives §7)
| Item | Spec | Qty | ₹ | Source |
|---|---|---|---|---|
| White LED | 3 W high-power **cool white** on 20 mm star | 4 | 40 ea | Robu/Amazon.in |
| Blue LED | 3 W **royal blue ~450 nm** on 20 mm star | 2 | 50 ea | Robu/Amazon.in (aquarium/grow LEDs) |
| LED CC driver | PT4115-based buck LED driver (350–700 mA), 12 V in | 2 | 60–120 ea | Robu/Amazon.in |
| LED optics | 20–30° lens + holder for 20 mm star | 6 | 20 ea | Amazon.in |
| LED-gate MOSFET | Logic-level N-MOSFET (AO3400/IRLZ44N) module | 2 | 80 | Robu |
| Small heatsink / Al plate | for LED stars | 1 | 100 | local |

---

## 6. Power system 🛒 (see protection passives §7)

**Pinned by a real daily-energy-budget calculation (12 Aug, revised same day to the smallest safe sizing) —
see `hardware/bom/eletect-x-power-budget.xlsx` for the live, editable model and sources.**

| Item | Spec | Qty | ₹ | Source |
|---|---|---|---|---|
| Battery | **4S LiFePO4 12.8 V, ~6 Ah**, integrated BMS (3-day autonomy, 85% DoD) | 1 | 1,799 | [Robu.in](https://robu.in/product/pro-range-ifr-32650-12-8v-6000mah-3c-4s1p-lifepo4-battery-pack/) — verify BMS/protection before ordering |
| BMS | not needed separately — covered by the battery's integrated BMS | — | — | — |
| Solar charge controller | **PWM/MPPT, explicit LiFePO4 profile**, ≥10 A | 1 | 1,949 | [amiciSmart 10A, Amazon.in](https://www.amazon.in/amiciSmart-Charger-Controller-Intelligent-Regulator/dp/B07T8LBN9J) — In Stock, selectable "b05: LiFePO4" mode confirmed. (Sparkel SPSCC-MPP1220Li was the better spec match but out of stock; Robu's ₹334 unit is lead-acid only — do not use.) |
| Solar panel | **12 V, 20 W** poly | 1 | 899 | [WAAREE, Amazon.in](https://www.amazon.in/WAAREE-polycrystalline-Performance-Warranty-Everyday/dp/B0DJJNS73C) — In Stock (Robu/Loom 20W options confirmed out of stock 13 Aug) |
| Reverse-polarity | Schottky diode **SB5100 (5 A)** *or* P-MOSFET ideal-diode | 1 | 20–60 | Robu |
| Fuse + holder | 5 A blade fuse + inline holder | 1 | 40 | Amazon.in |
| Load-switch MOSFETs | N-MOSFET modules (AO3400/IRLZ44N) for camera/IR/amp/LED rails | 3–4 | 80 ea | Robu |
| Supercap (optional) | 3× 10 F 2.7 V (series) for pulse buffer | 1 set | 200 | Robu *(optional for prototype)* |
| VIN wiring | connect 12.8 V → UNO Q **JANALOG VIN** (7–24 V); silicone wire + XT30/JST | — | 100 | local |

---

## 7. ⭐ PASSIVES & SEMICONDUCTORS — complete list (buy a resistor + cap kit, plus these specifics)

**Easiest: buy an assorted 1/4 W resistor kit + assorted ceramic + film cap kit (₹300–600 total) — it covers most values below.** Then buy these specific parts:

### Resistors (1/4 W, 1% where analog)
| Value | Qty | Use |
|---|---|---|
| 100 Ω | 4 | geophone series protection (×2), MOSFET gate (×2) |
| 1 kΩ | 2 | INA333 gain Rg (×100); spare |
| 3.3 kΩ | 1 | geophone damping (across coil) |
| 10 kΩ | 4 | Vref divider (×2), SDZ pull, spare |
| 33 kΩ | 2 | band-pass low-pass (50 Hz) |
| 100 kΩ | 4 | band-pass high-pass (2 Hz) ×2, MOSFET gate pulldown ×2 |
| 1 MΩ | 2 | geophone bias to Vref |
| 100 kΩ | 2 | (extra pulldowns) |

### Capacitors
| Value | Type | Qty | Use |
|---|---|---|---|
| 0.68 µF | film | 2 | band-pass high-pass (2 Hz) |
| 0.1 µF (100 nF) | film/ceramic | 2 | band-pass low-pass (50 Hz) |
| 100 nF | ceramic | 6 | decoupling (INA333, op-amp, MCUs) |
| 10 µF | electrolytic/ceramic | 4 | Vref filter, rail decoupling |
| 470 µF–1000 µF, 25 V | electrolytic | 2 | amp/LED rail bulk decoupling |

### Diodes / TVS / MOSFETs
| Part | Qty | Use |
|---|---|---|
| **Bidirectional TVS ~5–6 V** (e.g., SMAJ5.0CA / P6SMB6.8CA) | 3 | geophone input surge/ESD (2 to GND + 1 across) |
| **TVS ~18–24 V** (SMBJ18A/SMBJ24A) | 2 | solar + battery input surge |
| **Schottky SB5100 (5 A)** | 1 | reverse-polarity (or P-FET) |
| **AO3400 / IRLZ44N** logic-level N-MOSFET | 6–8 | IR gate, LED gate, load switches (buy a few spare) |
| 1N4148 signal diode | 4 | misc protection/flyback |
| Green/Red status LED (3 mm) + 1 kΩ | 2 | on-board diagnostics (optional) |

---

## 8. Environmental / sensors 🛒
| Item | Spec | Qty | ₹ | Source |
|---|---|---|---|---|
| BME280 | temp/humidity/pressure (I²C/Qwiic) | 1 | 250–400 | Robu/Amazon.in |
| IMU (tamper) | LSM6/ MPU-6050 (I²C) *(optional)* | 1 | 150–300 | Robu |
| Electret mic + preamp | MAX9814 module — MCU always-on gunshot *(optional)* | 1 | 150–250 | Robu |

---

## 9. Enclosure & mechanical 🛒 (print in-house PETG)
| Item | Spec | Qty | ₹ | Source |
|---|---|---|---|---|
| PETG filament | 1 kg (main body + modules) | 1 | 1,000–1,500 | Amazon.in |
| Silicone O-ring cord | 3 mm, ~2 m (gaskets) | 1 | 150 | Amazon.in |
| Pressure vent | e-PTFE / Gore-type vent (or PTFE membrane) | 1 | 150–400 | Amazon.in |
| Mounting bracket | SS-304 bracket / U-bolt (60–110 mm pole) | 1 | 300–600 | Amazon.in / hardware |
| Cable glands | PG7/PG9 IP68 | 4 | 30 ea | Amazon.in |
| Aviation connector | GX16 (expansion port) *(optional, for future pods)* | 1 | 150 | Amazon.in |
| Heat-set inserts | brass M3 ×10, M4 ×4 | 1 set | 200 | Amazon.in |
| Screws | SS-304 M3/M4 assortment + tamper bit | 1 set | 200 | Amazon.in |
| Stainless straps / ties | for pole + cable | few | 150 | local |
| Desiccant packs | silica gel | few | 50 | local |

---

## 10. Cost summary (one prototype node)
| Block | ~₹ |
|---|---|
| Camera + IR | 6,600 |
| Geophone chain | 1,300 |
| Audio deterrence | 1,300–2,300 (Ahuja SUH-15, ADR 0003/0005) |
| Visual deterrence | 900 |
| Power system | 4,500 |
| Passives/semis kit | 700 |
| Environmental | 500–900 |
| Enclosure/mech | 2,600 |
| **Total (already-owned excluded)** | **≈ ₹18,000–20,000** |
*(You already own UNO Q, LoRa, TPA3116, INMP441, INA333, geophone → those aren't re-counted.)*

---

## 11. Order-now checklist (freeze)
1. ☐ **Camera:** Arducam **IMX462 board — ASIN `B0CQ4QDCXN`** (NOT the ₹5,932 `B0829HZ3Q7`, which is OV2710). Try Amazon.in ASIN search → Robu → metal-case B0490 ₹8,680. Match IR to sensor (IMX462→940 nm). *(+1 spare if budget allows.)*
2. ☐ **940 nm IR illuminator board (12 V)** + N-MOSFET.
3. ☐ **DFPlayer PRO** + **8 Ω horn** (Ahuja SUH-15, flush-mount per ADR 0003 — see ADR 0005 for why the TOA SC-610 detour was reverted).
4. ☐ **LEDs:** 4× 3 W white + 2× 3 W royal-blue stars + 2× PT4115 drivers + 6× lenses + MOSFETs.
5. ☐ **Power:** 4S LiFePO4 pack + BMS + MPPT (LiFePO4) + 20 W panel + Schottky + fuse + load-switch MOSFETs.
6. ☐ **Geophone burial:** shielded cable + PVC pipe/caps + SS spike + Araldite + M12 + HDPE conduit + MCP6002.
7. ☐ **Passives:** resistor kit + cap kit + the specific R/C/TVS/MOSFET list in §7.
8. ☐ **Sensors:** BME280 (+ optional IMU, electret mic).
9. ☐ **Enclosure:** PETG + silicone cord + PTFE vent + SS bracket + glands + inserts + screws + acrylic window.
10. ☐ **Confirm** you have: UNO Q, Grove LoRa-E5, TPA3116, INMP441, **INA333** (verify), geophone.

**After these land → freeze the BOM and start building.** Everything is India-sourced, no imports, deadline-safe (camera ships now).

## Sources
[Arducam IMX462 day/night USB **board** B0CQ4QDCXN](https://www.amazon.com/Arducam-Computer-Automatic-Switching-All-Day/dp/B0CQ4QDCXN) · [same on Robu.in](https://robu.in/product/arducam-1080p-day-night-vision-usb-camera-2mp-infrared-webcam-with-automatic-ir-cut-switching-and-ir-leds/) · [Ahuja SUH-15 horn ₹1,299](https://www.moglix.com/ahuja-15w-horn-speaker-suh-15/mp/msnr50n423r251) · [Araldite (Amazon.in)](https://www.amazon.in/Araldite-Standard-Epoxy-Adhesive-90gm/dp/B08FHBFY27) · [shielded 2-core cable (Amazon.in)](https://www.amazon.in/Shielded-Signal-transmission-protection-Length/dp/B07DWVY8FT)

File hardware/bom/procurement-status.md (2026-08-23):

# EleTect X — Procurement Status (live tracker)

Supersedes the ✅/🛒 markers in `bom.md` for current status; `bom.md` stays the spec/pricing reference.
Snapshot taken **28 Jul 2026**. Update this file directly as orders land — don't let it go stale like the
old BOM markers did.

Legend: **H** = in hand · **O (date)** = ordered, expected that date · **T** = to order · **L** = to order,
local store only (not worth an online search, per prior sourcing attempts this session)

---

## 1. Compute, comms, core
| Item | Status | Note |
|---|---|---|
| Arduino UNO Q | **H** ×2 (2GB + 4GB) | Second unit = permanent bench/dev board — never touch the field-bound one once flashed. Genuinely useful given the Aug 8 freeze discipline. |
| Grove LoRa-E5 (IN865) | **H** | — |
| SenseCAP SX1302-4G gateway | **H** — ⚠️ **labeled EU868, architecture requires IN865** | See §Flags below — verify before relying on it. |
| XIAO ESP32S3 + Wio-SX1262 (Meshtastic kit), Wio Tracker L1 | **H**, not in current architecture | Meshtastic ≠ the frozen LoRaWAN IN865 design (ADR 0002). Keep as spares/future-pod hardware; don't let it scope-creep the build. |
| TPA3116D2 amp | **H** | — |
| INMP441 mic | **H** ×2-3 | — |
| INA333 | **H** | — |
| ADS1115 | **H** | Confirmed needed — bench ADC stand-in for the geophone front-end per the build schedule. |
| SM-24 geophone | **H** | — |
| USB hub | **H** | Bridges the IMX462's USB-A UVC connector to the UNO Q's single USB-C port for bench validation (build call 3's camera check). Not part of the final field enclosure — a compact USB-C-to-USB-A pigtail is the likely permanent fit once the camera path is proven. |
| Arducam IMX462 | **H** | No stand-in needed — real camera already in hand. |

## 2. Camera + IR
| Item | Status |
|---|---|
| 940nm IR illuminator board | **O — 5 Aug** |
| IR-gate MOSFET | **H** (IRLZ44N, consolidated — see §7) |
| Optical window (acrylic/PC 2-3mm) | **T** — local |

## 3. Geophone burial chain
| Item | Status |
|---|---|
| 2-core shielded cable | **O — 6 Aug** |
| PVC pipe 32mm + end caps | **T** — local |
| SS-304 bolt M10×100 (spike) | **T** — local |
| Araldite epoxy | **T** — local |
| HDPE conduit 20mm | **T** — local |
| MCP6002 (band-pass op-amp) | **O — 4 Aug** |
| PG7 gland (outdoor entry) | **H** ×5 |

## 4. Audio deterrence
| Item | Status |
|---|---|
| DFPlayer Mini | **H** — bench stand-in |
| DFPlayer PRO | **O — 4 Aug** |
| Ahuja SUH-15 horn | **O — ~30-31 Jul** (2-3 days out) |
| Speaker wire | **H** (silicone wire stock covers this) |

## 5. Visual deterrence (LED)
| Item | Status |
|---|---|
| Cool-white 3W LED star ×4 | **O — 5 Aug** |
| Royal-blue 3W LED star ×2 | **O — 2 Aug** |
| XL4015 buck driver ×2 (+1 spare) | **O — 30 Jul** |
| Heatsink puck ×6 | **O — 5 Aug** |
| Thermal adhesive tape | **O — 2 Aug** |
| Steko lens+holder | dropped — not needed |

## 6. Power system — **revised 13 Aug against the Aug 20 deployment deadline**

Sized 12 Aug against a real daily energy budget (baseline-dominated by ADR 0008's measured 0.42-0.45W
MPU-suspend draw, ~13Wh/day, plus event-triggered deterrence load) and real Kerala monsoon-season solar
irradiance, not the annual average. Revised same day to the smallest sizing that's still safe (3-day no-sun
autonomy, 85% DoD). Full calculation, formulas, sensitivity table, and sources:
`hardware/bom/eletect-x-power-budget.xlsx`.

**13 Aug: dropped the "smart" solar charge controller category entirely.** Every purpose-built LiFePO4-aware
unit checked failed real verification: the amiciSmart 10A (₹1,949) has a self-contradicting listing (its own
"Product description" says lead-acid only, contradicting its "About this item" b05 claim), mixed real customer
reviews on 4S packs specifically ("unavailable to charge lifepo4 battery pack of 4S" — verified purchase), and
a separately reported firmware bug (won't auto-resume charging after a low-voltage shutdown — disqualifying
for unattended field hardware on its own). Sparkel's SPSCC-1012LiMPPT (₹2,450, genuinely well-engineered,
IP67, real redundant protection) ships factory-default to **Gel lead-acid**, not Lithium — the "S-Unit" remote
needed to reconfigure it isn't sold anywhere on Sparkel's own site. Victron's Bluetooth-programmable units are
the one category that passed every check but cost ₹6,300+, well outside budget.

**Replacement: XL4015 CC/CV buck module, already in hand (bought 28 Jul).** Set manually to 14.2V output
(conservative vs the 14.6V absorption max, for margin against trimmer-pot drift and less full-charge calendar
stress) with current limit set to ~1-2A, verified with a multimeter before connecting to the pack — fully
inspectable, no firmware to trust. Trade-off, accepted deliberately: no staged bulk/absorption/float charging
and no independent hardware overvoltage backstop from the charge side — the **battery's own BMS becomes the
load-bearing safety component**, see battery row below. This also drops ~₹1,900-2,450 from the original plan.

| Item | Status | Spec pinned by the calc | Real product / decision (13 Aug) |
|---|---|---|---|
| 4S LiFePO4 battery | **O — 14 Aug, ⚠️ delivery risk accepted** | **~6Ah** (design daily need ~19.5Wh incl. 25% margin, x3 days no-sun autonomy, 85% DoD → 5.4Ah, round up). | **[Robu.in Pro-Range IFR 32650 12.8V 6000mAh 3C 4S1P LiFePO4](https://robu.in/product/pro-range-ifr-32650-12-8v-6000mah-3c-4s1p-lifepo4-battery-pack/)**, ₹1,799 (₹1,699 with Robu Points). Ordered 14 Aug accepting the delivery risk (Robu's own checkout quotes **5-7 working days**, realistically Aug 21-24 from this date, worse with their 15-17 Aug "Freedom Sale" — genuinely may miss Aug 20). Picked over ELBOTICS (₹2,399, Prime-confirmed 16 Aug) deliberately: Robu's 75×70mm form factor fits directly inside the main enclosure as originally designed (ELBOTICS's 150×65×100mm brick would've forced a separate base-mounted battery box with its own gland/cable run — one more sealed interface and connector pair, undesirable given the horn already went external per ADR 0011). Also has real engineering advantages once landed: 3C discharge rating gives 5.1x margin over our 3.52A peak load vs. ELBOTICS's 1.7x, and it's the pack the permanent build was already sized around. **Action: call Robu support (1800 266 6123) — confirm the real BMS cutoff-voltage spec (their sheet only says "BMS: Y") and ask if expedited shipping is possible given the date.** If it doesn't land by Aug 19, fall back to deploying whatever's in hand or accept a late start within the 10-day window. |
| Solar charge regulation | **H** — already own one (28 Jul) | Set to CV 14.2V, current-limited ~1-2A, verified by multimeter before connecting battery | XL4015 CC/CV buck (see reasoning above). Buy 1-2 more as spares — [Robu.in LM2596S](https://robu.in/product/lm2596s-dc-dc-buck-converter-power-supply/)-class module or the [Robocraze XL4015 5A, Amazon.in](https://www.amazon.in/Robocraze-Lithium-Battery-Charging-Converter/dp/B07RKH7YVY), ₹259, Prime, 2-day delivery — cheap insurance, arrives well before the 20th. |
| **Solar panel** | **T — source locally this week** | 15W clears the monsoon-derated need theoretically; **20W is the realistic smallest buy** (~2.48x margin), 10W workable at tighter ~1.24x margin if that's what's available | No online 12V panel reliably lands by Aug 20 (10+ alternatives checked, earliest Fri-Sun 22-23 Aug). **Plan: buy a 12V/15-20W panel in person at an electronics/solar shop in Malappuram or Kochi this week** — sidesteps shipping lead time entirely, ~₹700-1,500. The [WAAREE 20W panel already ordered](https://www.amazon.in/WAAREE-polycrystalline-Performance-Warranty-Everyday/dp/B0DJJNS73C) (₹899, lands Mon 24 Aug) is too late for the trial — keep it, don't cancel, it becomes the Phase 2/permanent-build panel. |
| Fuse + holder | **T** — buy locally, not online | **Revised to 6A** (14 Aug) — 5A's margin over the worst-case peak (45.1W) shrinks to just 1.11x at low battery voltage (~10V, 4.51A), below the design's own 1.25x safety convention. 6A restores real margin across the full discharge range at no extra cost. | Every Amazon/Robu inline blade fuse holder checked quotes delivery Aug 21-23. Ubiquitous, cheap part (any electronics/automotive-spares shop) — **source locally**, ~₹100-150. |
| Power switch | **T** — buy locally, reverted 14 Aug (bad online listing spec) | SPST, simple 2-position ON/OFF (not ON-OFF-ON), rated ≥10A/12V DC, panel-mounted | The [Electronic Spices 5PCS rocker switch, Amazon.in](https://www.amazon.in/s?k=12V+DC+toggle+switch+SPST&rh=p_n_delivery_date%3A1) pick was checked against its real spec sheet and rejected: it's actually a **3-position ON-OFF-ON switch** (wrong type — wastes/misuses positions for a simple power cutoff), and its "10 Amps" rating is paired only with "250 Volts," reading as an AC rating with no stated 12V DC figure. **Source locally instead** — ask for a simple SPST toggle/rocker switch, 2-position ON/OFF, rated ≥10A at 12V DC (any electronics or automotive-spares shop stocks this, ~₹30-100). Lets you physically confirm position count and DC rating before buying, which online listing text has twice failed to state clearly. Panel-mount via a cut hole in the enclosure wall (rocker style) or drilled hole + nut (toggle style); seal with a thin bead of silicone around the mounting point either way. Wire: battery+ → fuse → switch → WAGO splice point → branches. |
| USB-C→USB-A adapter (camera) | **O — 15 Aug** | Passive adapter only — board sources camera power itself via VBUS back-drive, see Buck audit below | **[Amkette USB 3.0 Type-C Male to USB-A Female OTG Adapter, Amazon.in](https://www.amazon.in/s?k=USB+C+male+to+USB+A+female+OTG+adapter)** — ₹99, 4.4★ (773 reviews), 400+ bought in past month, delivers tomorrow (15 Aug). Picked over the AGARO/Portronics/Ambrane alternatives specifically because its title states the orientation unambiguously ("Type-C **Male** to USB-A **Female**") — most competing listings phrase this ambiguously ("Type C Female to USB Male"), which is backwards-sounding for our use case and risks ordering the wrong orientation. **For resilience: don't let it hang loose on the port** — zip-tie or hot-glue-dab the adapter body to a fixed point near the port so there's no cantilever stress on the connector under vibration. |
| VIN connection (board-side) | **T** — reverted 14 Aug on cost, jumper + hot glue instead of screw shield | VIN is a through-hole pin on the standard shield-style power header — don't solder wire directly to the board | **Female-to-female jumper wires (already have spare stock/cheap to add) + hot glue for strain relief**, not the ₹282 screw shield. Push the jumper socket fully onto the VIN and GND pins, verify a solid connection with a multimeter, then dab hot glue over the joint to lock it in place mechanically — prevents the connector working loose from vibration without paying for a dedicated part. Real trade-off, accepted for this trial: hot glue secures the wire's *position*, not the *contact quality* at the pin itself, the way a screw terminal's physical clamp does — genuinely fine for a 10-day run, worth upgrading to the screw shield for Phase 2's permanent build where the connection needs to survive years, not days. |
| Separate BMS | not needed — battery's BMS confirmed via label + listing | — | — |
| Load-switch MOSFETs | **H** (IRLZ44N, see §7) | — | — |
| Supercap (optional) | skip for now — revisit only if bench testing shows a brownout on deterrence burst | — | — |
| VIN wiring (silicone wire + XT30) | **H** — XT30UD pair ×2 already in hand from the Robu order | — | — |
| Buck converters (TPA3116D2/IR illuminator insurance) | **O — 14 Aug** — bundled into Robu order #3636219 with the battery | Only needed if either board's real input-voltage tolerance falls below the LiFePO4 pack's 14.6V absorption peak (open verification item, see below) | [Robocraze XL4015, Amazon.in](https://www.amazon.in/Robocraze-Lithium-Battery-Charging-Converter/dp/B07RKH7YVY), ₹259 each, Prime — same part as the solar-charging module, buy extras in one order. |
| Bench charger (optional, no longer required) | dropped — the XL4015 solar-charging path covers initial charge-up too | — | Robu's "Battery Charger 4S LiFePO4 -14.5V 1A" (₹700) is no longer needed unless a bench-only backup charge path is wanted. |

**Aug 20 deadline — decided 14 Aug.** This is a 10-day contest trial (deploy, retrieve, review footage), not
yet the permanent install, which changes the risk calculus on both remaining items:
1. **Battery: ordered from Robu 14 Aug, accepting the delivery-timing risk** (see row above) — chosen for the
   compact form factor and discharge margin over the delivery-certain but bulkier/tighter-margin ELBOTICS
   alternative. A 6Ah pack alone, no solar, covers ~3.3 days at the design 85% DoD (65.3Wh usable ÷ 19.47Wh/day
   design load) — not the full 10 days by itself, which is exactly why the panel below still matters.
2. **Solar panel: source locally in Malappuram/Kochi this week** — the actual fix for continuous 10-day
   coverage, since no online 12V panel option lands in time. This is now the primary plan, not a fallback.

**If either slips past Aug 19:** deploy on whatever's in hand and accept partial coverage (battery-only ≈3-4
days of the 10, or delayed start) rather than blocking the whole trial — no additional cost either way.

**Revised total, power block only:** ≈₹2,600-3,450 (battery ₹1,799 + local panel ₹700-1,500 + fuse/holder
~₹100-150 local), not counting the already-sunk WAAREE panel (₹899, held for Phase 2) or the optional spare
XL4015 bucks (₹259-518, only if the TPA3116D2/IR illuminator verification below calls for them) — the cheapest
version of this plan yet, versus the original ₹5,994.

**Buck/regulation audit (13 Aug), all subsystems:**
| Subsystem | Needs a buck? | Why |
|---|---|---|
| LEDs (cool-white/royal-blue) | No — already covered | XL4015 buck driver ×2 already sourced (§3, ordered 30 Jul) |
| UNO Q | No | Confirmed via official Arduino power spec — VIN accepts 7-24V DC, onboard LMR51440 bucks to 5V internally |
| Camera (Arducam IMX462) | No | Powered off USB-C, board-regulated |
| DFPlayer PRO, INA333, ADS1115, LoRa-E5, INMP441, BME280/MPU-6050 (if used) | No, presumed | All draw from the tray's own regulated rails off the UNO Q/perfboard, not directly off the raw battery bus — not yet re-verified against each individual datasheet's absolute max input, worth a quick pass once the tray is populated but not expected to be an issue |
| **TPA3116D2 amp (XH-M543 120W board)** | **Resolved 14 Aug — no buck needed** | Listing spec: Operating Voltage Range 12-24V DC, usage note tolerates DC12V-26V on the input terminal. 14.6V absorption peak sits comfortably inside this range (1.64x margin to the 24V rated max). Wire straight to the battery bus. |
| **940nm IR illuminator board (VISTORA 48-LED, ASIN B0H2DQ9DVK, already purchased 28 Jul)** | **Resolved 14 Aug — buck IS needed** | Listing states a single fixed **Input Voltage: DC12V** (not a range), 300mA draw. The 14.6V absorption peak exceeds this by ~22% — real overvoltage risk to a board with no stated input tolerance margin. **Use one spare XL4015 buck inline, set to ~12V**, ahead of this board specifically. |

Both open items now resolved with real listing data — one spare buck is genuinely needed (IR illuminator),
the amp is fine wired directly to the battery bus. Only need to buy 1 spare XL4015 (₹259), not 2.

## 7. Passives & protection
| Item | Status |
|---|---|
| Resistor kit | **H** |
| Cap kit | **H** |
| 0.68µF film cap ×2 | **O — 30 Jul** |
| 1N4148 ×4 | **H** |
| P6KE18/24CA TVS ×2 | **O — 2 Aug** |
| P6KE6.8CA TVS ×3 | **O — 15 Aug** — Robu, exact part match found, no longer local-only |
| SB5100 Schottky ×1 | **O — 15 Aug** — Robu, exact part match found, no longer local-only |
| IRLZ44N MOSFET | **H** ×5-7 + **O — 14 Aug** top-up bundled into Robu order #3636219 — margin restored, no longer tight |
| LR7843 MOSFET control module | **H** ×1 | Pre-built module, screw terminals — fits the "no PCB fab" constraint better than a bare IRLZ44N for at least one load-switch position. See §Flags. |
| Status LEDs 3mm + 1kΩ | **H** ×2 |

## 8. Environmental sensors
| Item | Status |
|---|---|
| BME280 | **H** |
| MPU-6050 | **H** |
| Electret mic + MAX9814 | **dropped** — see §Flags |

## 9. Enclosure & mechanical
| Item | Status |
|---|---|
| PETG filament 1kg | **H** |
| Silicone O-ring cord | **O — 15 Aug** — SOMA, onlyscrews |
| e-PTFE vent | **O — 4 Aug** |
| SS-304 bracket/U-bolt (main enclosure pole mount) | **O — 15 Aug** — Bectro pole clamp |
| SS-304 bracket/U-bolt (horn pole mount) | **O — 15 Aug** — second Bectro clamp, same part, reused per ADR 0011 horn split |
| PG7/PG9 glands | **H** ×5 each |
| Brass heat-set inserts (onlyscrews) | **O — 15 Aug** | M3-only, "3D Printing" slant-knurled line. Qty 10 each: [M3x4mm](https://onlyscrews.in/products/m3-x-4mm-3d-printing-brass-threaded-inserts-dia-3mm-length-4mm) ₹4.40, [M3x5mm](https://onlyscrews.in/products/m3-x-5mm-3d-printing-brass-threaded-inserts-dia-3mm-length-5mm) ₹4.60, [M3x6mm](https://onlyscrews.in/products/m3-x-6mm-3d-printing-brass-threaded-inserts-dia-3mm-length-6mm) ₹4.80 — ~₹138 for 30 pieces. |
| SS-304 screws (onlyscrews) | **O — 15 Aug** | 1x [M3 Allen Button Head SS304 Assorted Box](https://onlyscrews.in/products/m3-allen-button-head-ss304-assorted-box) (₹240) + individual top-up **M3×8/10/12mm ×15 each** (~₹96) — total ~₹336. |
| VHB double-sided mounting tape (onlyscrews) | **O — 15 Aug** | 3M VHB, transparent 4910 variant for clean bond line — mounts components without screws where a boss isn't practical. |
| M3 standoff spacers (Robu) | **O — 15 Aug** | M3×15mm nylon + M3×5mm brass hex — perfboard solder-joint clearance, camera/IR window offset, UNO Q underside clearance. |
| Desiccant packs | **O — 30 Jul** |

## Already in hand, off the original checklist (Robu wire/connector order)
16AWG silicone wire, 22AWG 2-core, 18AWG PTFE (red+black), 26AWG 4-core, 26AWG 3-core, 26AWG 2-core,
26AWG 5-colour kit, XT30UD pair ×2, JST XH 2/4/6-pin sets, WAGO lever splice connectors (2/3/5-way),
GRM155 0402 SMD 2.2µF cap ×3 (SMD — bench reference only, not usable given no-PCB-fab constraint, low
stakes either way), PG7/PG9 glands (additional stock), LR7843 module.

---

## Flags — need a decision, not just a status

1. **LoRa gateway region mismatch.** CONTEXT.md and the frozen architecture specify **IN865**
   (868MHz is illegal to transmit on in India). The SenseCAP gateway in hand is labeled **EU868**.
   IN865's channel plan (865.0625-867.9MHz) sits inside EU868's typical RF front-end passband
   (863-870MHz), so the hardware may well work once ChirpStack is configured with the IN865 region
   profile — SenseCAP's SX1302 gateways are often software-region-selectable within their filter's
   range — but "may well work" isn't good enough to discover on field-test day. **Action: power it up,
   set the ChirpStack region profile to IN865, and run a real join test with the Grove E5 this week** —
   this is cheap to check now and expensive to find out wrong on Aug 9-14.
2. **INMP441 vs. MAX9814 — good catch, dropping MAX9814.** They weren't redundant purchases of the same
   thing: INMP441 (I2S digital) is the architecture's one acoustic-corroboration sensor (CONTEXT.md §3);
   MAX9814 was listed as an *optional* second, analog, MCU-native mic for a lighter-weight always-on
   listen path. You already have 2-3 INMP441 units and it's marked optional in the original BOM for a
   reason — one sensor doing the job cleanly beats two doing it redundantly (CONTEXT.md §7, "reject
   gimmicks"). Dropped — removed from §8 above, no purchase needed.
3. **IRLZ44N quantity is tight (5-7 in hand vs. ~6-7 needed), not comfortably spare.** Two ways to close
   the gap without a new order: use the **LR7843 module** you already have for one of the load-switch
   positions (camera or IR rail — it's a pre-built screw-terminal switch module, which is a better fit
   for the "no PCB fab" constraint than hand-wiring another bare IRLZ44N with gate/pulldown resistors
   anyway), or add a couple more IRLZ44N to whatever's next Robu order to restore real spare margin.
4. **Battery purchase resolves two BOM lines at once** — buying a pack with integrated BMS (as already
   recommended earlier this session) means §6's "Separate BMS" line disappears entirely; don't shop for
   it separately.

## Priority order for what's still unordered

1. **Order the power system today.** Battery + MPPT + panel + fuse are the only block with zero orders
   placed, they're the longest remaining lead-time item, and Day "Mon 3 Aug" in `BUILD_BLUEPRINT_AUG8.md`
   already assumes power is in hand and wired by then. Ordering today gives ~5-6 days of shipping slack;
   waiting even a few more days starts eating into that.
2. **Order enclosure hardware this week** (O-ring cord, SS bracket/U-bolt, brass inserts + screws via
   onlyscrews) — needed for the Aug 4-5 enclosure-assembly stage, not urgent today but shouldn't slip
   past this week.
3. **Local-store run this week, no shipping risk either way:** PVC pipe/caps, SS-304 spike, Araldite,
   HDPE conduit, P6KE6.8CA, SB5100, acrylic window — cheap, fast, no reason to wait.

## What this changes about the build schedule

Nothing, structurally — it confirms it. Every item already ordered lands between **30 Jul and 6 Aug**,
which is exactly `BUILD_BLUEPRINT_AUG8.md`'s Stage 2 window ("real hardware lands," Sun 2 – Wed 5 Aug).
None of it blocks Stage 0/1 (today through Sat 1 Aug), since that stage runs entirely on bench stand-ins
you already have in hand: ADS1115+INA333 for the geophone, DFPlayer Mini for audio, and the **real**
IMX462 for vision (no stand-in even needed there — camera's already in hand). Power is the one gap that
needs to close today to keep Stage 2's Aug 3 power-validation task on schedule.

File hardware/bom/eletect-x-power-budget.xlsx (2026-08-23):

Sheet: Assumptions
EleTect X — Power Budget Assumptions
Edit the blue Value cells. Yellow-filled rows are placeholder estimates (no site data yet) — revisit first.
Assumption | Value | Unit | Source / note
Board baseline power (MCU active, MPU deep-suspend) | 0.45 | W | ADR 0008 — real measured 0.42-0.45W @5.1V for this exact use case (continuous sensing, MPU woken only on event). Using worst case.
Sensor front-end + env sensor overhead | 0.08 | W | Estimate: INA333 + MCP6002 dual op-amp + BME280 + MPU-6050 quiescent draw, generous margin (each is sub-mA class).
LoRa idle/heartbeat energy | 0.05 | Wh/day | Estimate: Grove LoRa-E5 (STM32WLE5) TX ~120mA for well under 1s per uplink, ~15 uplinks/day. Effectively negligible either way.
MPU active power (camera streaming + inference) | 6.1 | W | Community-measured Arduino UNO Q camera-inference power draw (forum/review sources, 2026) — see Notes tab for links.
Tier-1 events/day (wake + vision-confirm, no deterrence) | 8 | count/day | PLACEHOLDER — no site-specific detection-rate data yet for this boundary. Adjust once field data exists.
Tier-1 MPU active duration | 90 | s | Estimate: suspend-resume + camera + inference + fusion decision, no deterrence hardware.
Tier-2 events/day (confirmed elephant, full deterrence) | 3 | count/day | PLACEHOLDER — same caveat as Tier-1. This is the single highest-leverage number in this sheet — revisit with real DFO/field data.
Tier-2 MPU active duration | 150 | s | Estimate: resume + camera + inference + fusion + bandit decision + LoRa alert.
Audio deterrence power (during blast) | 18 | W | TPA3116D2 into 8ohm Ahuja SUH-15 horn at ~15W rated acoustic output, ~92% Class-D efficiency (TI datasheet) -> ~16-18W input.
Audio duration per Tier-2 event | 15 | s | Estimate — single deterrence blast.
LED deterrence avg power (irregular strobe, ~55% duty) | 10 | W | Estimate: 18W nominal max string x approx duty cycle for an irregular (not continuous) strobe pattern per CONTEXT.md.
LED duration per Tier-2 event | 45 | s | Estimate.
LED max simultaneous power (all on, full rated current) | 18 | W | 4x3W cool-white + 2x3W royal-blue stars, nominal rated current (BOM section 5). Used for peak/fuse sizing, not daily energy.
IR illuminator power (during capture) | 3 | W | Estimate only — 940nm illuminator board is still on order (status O in procurement tracker). Confirm against real datasheet on arrival.
IR duration per Tier-2 event | 90 | s | Estimate — spans the camera-active portion of the event.
Design margin multiplier | 1.25 | x | 25% margin over the raw calculated total, for estimate uncertainty, cell aging, and temperature derate.
Battery usable depth of discharge (LiFePO4) | 0.85 | fraction | Raised from 0.8 to 0.85 (12 Aug revision, keep the system as small as possible). LiFePO4 tolerates this depth routinely; the node mostly floats near full charge off solar anyway.
No-sun autonomy target | 3 | days | Cut from 4 to 3 days (12 Aug revision, smaller-system request). Recommended floor, not lower - Kerala's monsoon produces genuine multi-week low-generation stretches, and this is a safety system real people rely on. See the sensitivity table on the Battery and Solar Sizing tab.
Battery nominal voltage | 12.8 | V | 4S LiFePO4 (3.2V/cell nominal) — CONTEXT.md section 3, frozen architecture.
Ernakulam/Kochi annual average peak sun hours | 4.6 | h/day | Web search, coastal Kerala solar-generation sources, 2026 — see Notes tab for links. Nearest available proxy to Kothamangalam.
Monsoon GHI derate (Jun-Sep) | 0.3 | fraction | Cited range is 25-35% GHI drop at south Indian coastal sites Jun-Sep. Using the midpoint, biased conservative since Kothamangalam sits nearer the Western Ghats and typically sees heavier monsoon rainfall than coastal Kochi.
System derate (MPPT + wiring + temp + soiling + angle losses) | 0.75 | fraction retained | Standard off-grid solar design derate — i.e. 25% total system loss between panel-rated W and energy actually reaching the battery.
Fuse safety margin over calculated peak load | 1.25 | x | Standard practice — fuse rated above worst-case peak draw, but still well under wire/connector/battery safe limits.

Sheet: Daily Energy (Wh)
EleTect X — Daily Energy Budget
All cells below are formulas driven by the Assumptions tab — change assumptions there, this recalculates.
Item | Calculation | Wh/day
Baseline (24h continuous — reflex layer always on)
Board baseline (MCU active, MPU deep-suspend) | board W x 24h | 10.80
Sensor front-end + env sensor overhead | sensor W x 24h | 1.92
LoRa idle/heartbeat | direct entry | 0.05
Baseline subtotal |  | 12.77
Tier 1 — MPU wake + vision-confirm, no deterrence
Energy per Tier-1 event | MPU active W x (duration s / 3600) | 0.15
Tier-1 daily energy | per-event Wh x events/day | 1.22
Tier 2 — confirmed elephant, full deterrence cycle
MPU active energy per event | MPU active W x (duration s / 3600) | 0.25
Audio deterrence energy per event | audio W x (duration s / 3600) | 0.07
LED deterrence energy per event | LED avg W x (duration s / 3600) | 0.12
IR illuminator energy per event | IR W x (duration s / 3600) | 0.07
Total energy per Tier-2 event |  | 0.53
Tier-2 daily energy | per-event Wh x events/day | 1.59
Event subtotal |  | 2.81
TOTAL daily energy (no margin) |  | 15.58
TOTAL daily energy (design figure, with margin) |  | 19.47

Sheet: Battery & Solar Sizing
EleTect X — Battery, Solar, MPPT, Fuse Sizing
Formula-driven from Daily Energy (Wh) and Assumptions tabs.
Item | Calculation | Value
Battery
Design daily energy | from Daily Energy tab (with margin) | 19.47
Battery capacity needed (Wh) | daily Wh x autonomy days / DoD | 68.72
Battery capacity needed (Ah) | Wh / nominal voltage | 5.37
Recommended battery capacity, rounded up | CEILING to next whole Ah | 6
Solar
Annual average peak sun hours (Kochi/Ernakulam proxy) | from Assumptions | 4.60
Monsoon-derated peak sun hours (design case) | annual PSH x (1 - monsoon derate) | 3.22
Minimum panel wattage needed (theoretical) | daily Wh / (monsoon PSH x system derate) | 8.06
15W panel — monsoon-day harvest | 15 x monsoon PSH x system derate | 36.23
20W panel — monsoon-day harvest | 20 x monsoon PSH x system derate | 48.30
Margin vs need — 15W panel | harvest / design daily need | 1.86x
Margin vs need — 20W panel | harvest / design daily need | 2.48x
Recommended panel: 15W (theoretical) / 20W (realistic purchase)
Reason (revised 12 Aug): 15W clears the monsoon-derated need with about 1.86x margin. In practice, small retail panels are commonly sold in 10W/20W steps, not 15W, so 20W (about 2.48x margin) is the realistic smallest purchasable size - see the Notes tab for a real Robu.in listing.
MPPT controller
Approx. charging current at 20W / battery voltage | panel W / battery V | 1.56
Recommended MPPT continuous rating (min, with margin) | approx current x 1.5 | 2.34
Must be explicitly LiFePO4-profile (absorption ~14.6V, float ~13.6V for 4S) and low quiescent current — a leaky always-on MPPT can itself eat into the small daily budget above.
Fuse (main battery-to-load protection)
Peak instantaneous load (MPU active + audio + LEDs max + IR, worst-case coincident) | sum of peak-draw assumption cells | 45.10
Peak current draw | peak W / battery V | 3.52
Recommended minimum fuse rating | peak current x safety margin | 4.40
Existing BOM fuse spec | hardware/bom/bom.md section 6 | 5
Margin of existing 5A fuse over calculated minimum | 5A / recommended minimum | 1.14x
Autonomy sensitivity (reference only - main figures above use 3-day / 85% DoD)
Scenario | Calculation | Battery (Ah, rounded up)
2 days no-sun (smallest, tighter monsoon risk) | daily Wh x 2 / 0.85 DoD / 12.8V | 4
3 days no-sun - RECOMMENDED | daily Wh x 3 / 0.85 DoD / 12.8V | 6
4 days no-sun (original, more conservative) | daily Wh x 4 / 0.85 DoD / 12.8V | 8
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

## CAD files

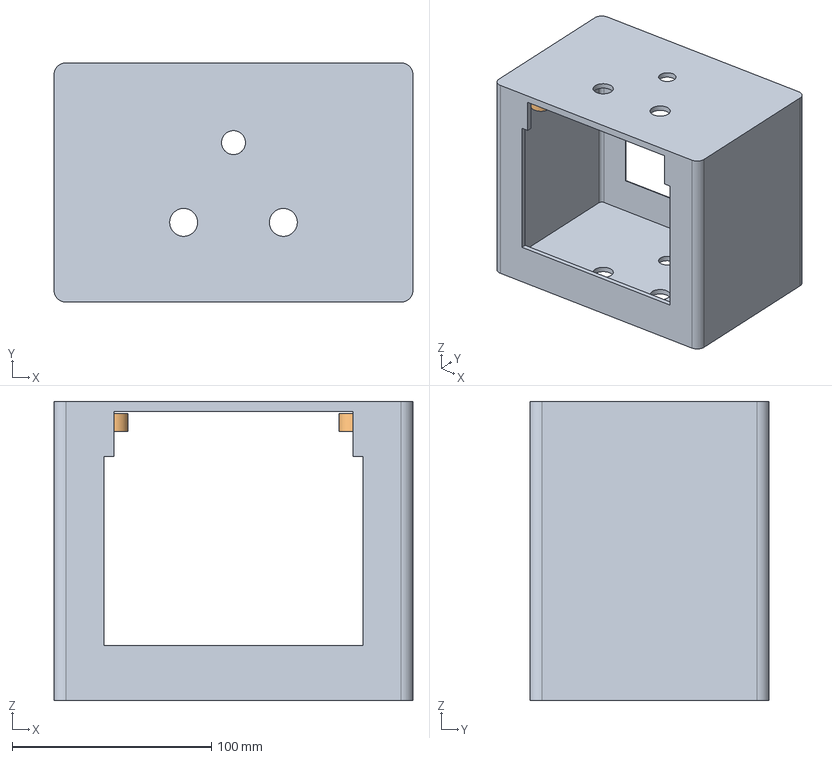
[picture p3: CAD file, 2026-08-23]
hardware/cad/main_enclosure_shell.step
180.0 x 120.0 x 150.0 mm

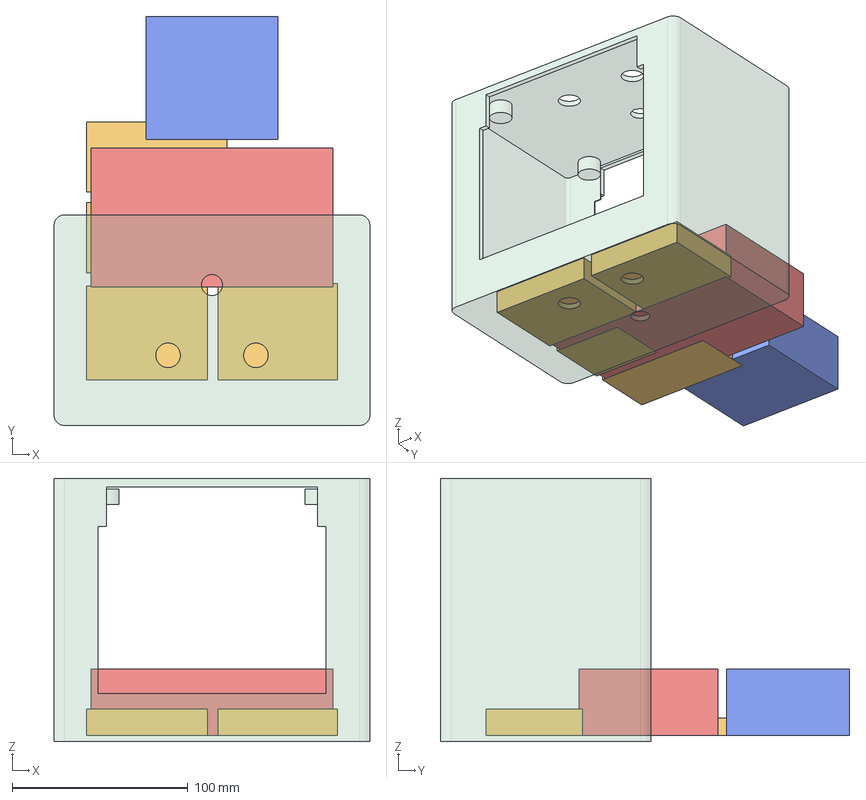
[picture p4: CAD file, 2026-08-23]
hardware/cad/main_enclosure_assembly.step
180.0 x 233.0 x 150.0 mm
main_enclosure_shell
reference_MPPT_controller
reference_battery_pack
reference_UNO_Q
reference_TPA3116D2_amp_board
reference_DFPlayer_PRO
reference_Grove_LoRa-E5
reference_Passives_perfboard_incl._INA333-ADS1115-passives

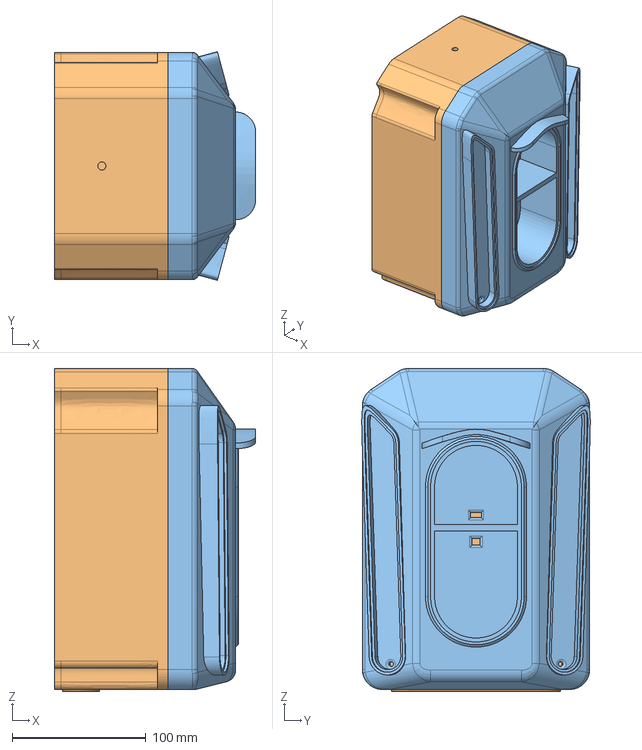
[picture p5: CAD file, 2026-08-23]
hardware/cad/eletect_x_final.step
150.5 x 171.0 x 241.5 mm

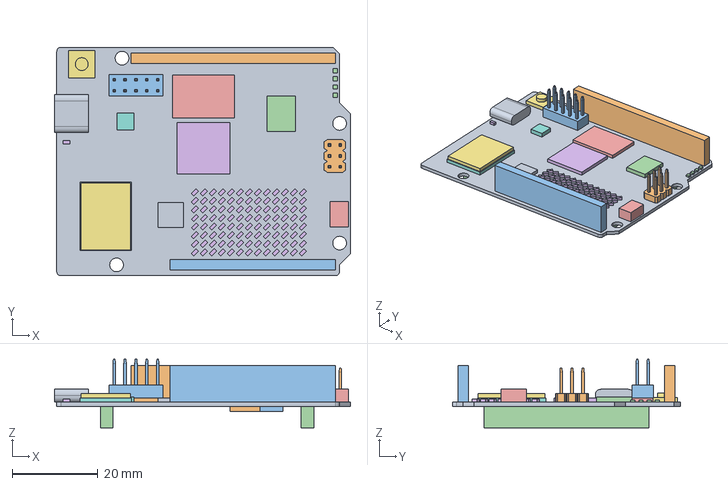
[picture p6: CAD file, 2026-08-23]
hardware/cad/imported_components/UNO Q simplified.stp
69.1 x 53.3 x 16.0 mm

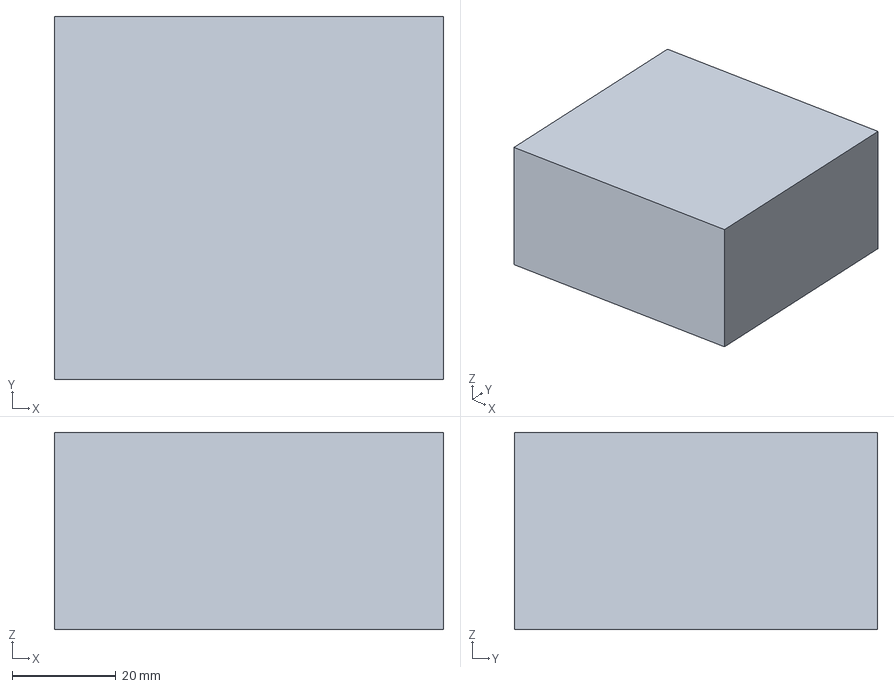
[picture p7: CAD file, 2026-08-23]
hardware/cad/reference_battery_pack.step
75.0 x 70.0 x 38.0 mm

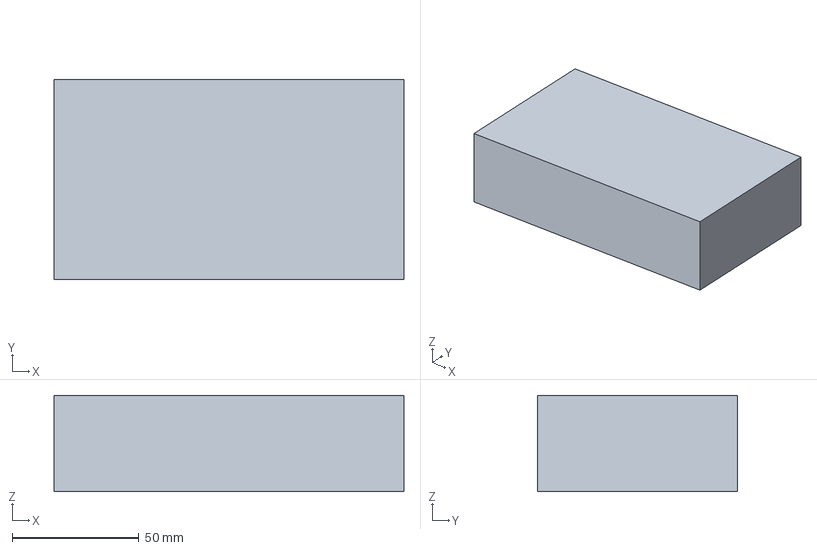
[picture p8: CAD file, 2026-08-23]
hardware/cad/reference_mppt_controller.step
138.0 x 79.0 x 38.0 mm

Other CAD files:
hardware/cad/eletect_x_final.f3z
hardware/cad/main_enclosure_shell.stl

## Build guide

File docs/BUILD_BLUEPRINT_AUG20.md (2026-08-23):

# EleTect X — Build Blueprint to Aug 20 (supersedes BUILD_BLUEPRINT_AUG8.md)

Written 14 Aug, 6 days out from the DFO Kothamangalam field deployment. `BUILD_BLUEPRINT_AUG8.md`'s
schedule is stale (dates in the past, MVP freeze didn't hit on 8 Aug) — this is the operative plan.
Cross-check against `HANDOVER.md` and `docs/KNOWN_GAPS.md` before starting any item below; both are
kept current and take precedence if this doc drifts.

Two real long-pole items drive the whole schedule: **the enclosure has zero CAD progress** (only the
markdown design doc exists, no Fusion 360 model/STEP/STL — modeling + print time is the biggest
schedule risk), and **`device/mpu/main.py` has no real integration loop** (everything downstream of
"sensor event happened" is unbuilt). Both start Day 0.

## Day 0 — Thu 14 Aug (today, remainder of)

- Call Robu (1800 266 6123) — check battery expedite status, order #3636219.
- Local-store run: optical window, PVC pipe+caps, SS-304 M10×100 spike, Araldite, HDPE conduit,
  12V/15-20W solar panel, 6A fuse+holder, SPST power switch. All local-only, no shipping risk.
- Bench-verify SenseCAP gateway region: power up, set ChirpStack region profile to IN865, run a real
  join test with the Grove LoRa-E5. Cheap to check now, illegal to get wrong later (868MHz un-transmit-
  legal in India).
- Bench-verify USB-C host-mode-under-VIN: confirm the IMX462 enumerates when the board is powered via
  VIN, not USB-C. If this fails, the vision architecture needs rework — find out today, not day 4.
- Start Fusion 360 modeling on the enclosure (main housing + horn housing per ADR 0011's split). This
  is the longest lead-time item on the whole list — start it in parallel with everything else, don't
  sequence it after firmware.

## Day 1-2 — Fri 15 / Sat 16 Aug

- Enclosure: finish both housing models, slice, start PETG prints (CR-M4 + Bambu A1). Budget real
  print-queue time — two enclosures, gasket channels, bosses, don't assume one shot prints clean.
- Firmware: build the real `device/mpu/main.py` sense→fuse→decide→actuate loop — the single biggest
  remaining software task. Wire Bridge `provide()` handlers on the MCU side (`drive_horn`, `drive_led`,
  `pulse_ir`, `geophone_ok`) to match.
- Firmware: fix the geophone sampling-cadence bug (`geophone_service()` sampling at loop rate instead
  of gated cadence).
- Firmware: resolve the LoRa `Serial`/`Serial1` conflict with Bridge before any further LoRa work.

## Day 3 — Sun 17 Aug

- Assembly: heat-set inserts into printed parts, mount boards on standoffs, wire the power system
  (XL4015 buck set to 14.2V, current limit verified with a multimeter *before* connecting the battery).
- Mount battery once it lands (delivery-risk item from Day 0's Robu call).
- Run the geophone bench stomp test — never run yet, validates STA/LTA thresholds against real footfall
  instead of synthetic data.

## Day 4 — Mon 18 Aug

- Full system integration test, end to end: geophone → MCU → Bridge → MPU fusion → decision →
  horn/LED actuation → LoRa uplink → Supabase → dashboard. First time every link in the chain has
  been exercised together.
- Weatherproofing pass: gasket seams, glands, e-PTFE vent, desiccant packs.

## Day 5 — Tue 19 Aug (buffer)

- Field rehearsal: pole-mount both housings, time the 3-person install, check solar charging under
  real sun.
- Buffer for whatever Day 4's integration test surfaces — expect it to surface something.
- Git hygiene: commit the real untracked work (ADR 0011, power-budget spreadsheet, UNO Q reference
  PDFs), spot-check the wider working-tree diff before committing (much of it may be line-ending
  noise, not real changes — verify, don't assume). Tag a pre-deployment freeze point.

## Day 6 — Wed 20 Aug

- Deploy with DFO Kothamangalam. 10-day trial begins.

## What happens after Aug 20

Field footage and the real deployment story are the primary material for both contest submissions —
Robu Arduino Physical AI Challenge (23 Aug) and Hackster "Invent the Future with UNO Q" (30 Aug). The
write-up pass leans on `edge-impulse-hackster-writeup` and should start as soon as footage is in hand,
not wait for the full 10-day trial to finish if a submission-worthy clip lands earlier.

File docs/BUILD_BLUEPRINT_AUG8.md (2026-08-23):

# EleTect X — Build Blueprint to Aug 8 (supersedes PROJECT_BLUEPRINT.md §6)

Read `CONTEXT.md` first. This document plans every remaining task from **today (Sun 26 Jul 2026)** to a
self-imposed **freeze on Sat 8 Aug**, ahead of the DFO field test and both contest deadlines. It replaces
the week-by-week table in `docs/PROJECT_BLUEPRINT.md` §6, which was written before this project's true
starting point was known. Everything else in `PROJECT_BLUEPRINT.md` (repo architecture, module map,
engineering principles) still stands.

## 0. Reality check — what's actually done vs. what's actually left

A repo scan, not a guess, is the basis for this plan:

**Done, and further along than the old roadmap assumed:**
`web/frontend` is a built, routed, RBAC'd React PWA — public marketing pages, auth (signup/officer-approval/
forgot-password), dashboard shell + modules (map, alerts, node detail, analytics, maintenance, fleet
health), admin user management, Demo Mode, CI (lint/typecheck/test), Vercel config, and four rounds of
QA screenshot passes already recorded under `docs/qa/`. `web/backend` has schema + RLS + three migrations
+ two edge functions (officer-request notification, alert fan-out with tests). `web/ingest` is a working
TypeScript service (MQTT → validate → Supabase) with a Dockerfile. `hardware/bom/bom.md` is a 178-line,
mostly-locked sourcing document. Four ADRs already exist recording real engineering decisions.

**Not started — this is the entire remaining critical path:**
`device/mcu`, `device/mpu`, and `ml` are empty except READMEs. Zero firmware, zero cognition code, zero
trained models. Robu's own rubric weights **Functionality & Execution at 40 of 100 points** — more than
Innovation, Documentation, and Presentation combined — and functionality lives entirely in these three
empty directories. **This is the headline fact driving this whole blueprint: the web app will not move
the needle further, the physical/firmware/ML stack is 100% of what's left to build, and it needs to go
from nothing to a bench-validated end-to-end loop in 13 days.**

## 1. Where Edge Impulse fits

Edge Impulse has confirmed, immediate support for the Arduino UNO Q, including its STM32U585 MCU side —
this is the direct mechanism for CONTEXT.md §4's "TinyML footfall" requirement. Use one Edge Impulse
project per on-device model, all under one account:

- **Seismic/footfall (STM32U585, primary):** feed it labeled STA/LTA feature windows from the geophone
  bench rig (ADS1115+INA333 stand-in, then real SM-24 once potted). Export as a C++ inference library,
  link into the Arduino-Core firmware. This is the lowest-risk, most spec-aligned use of EI.
- **Vision detector (QRB2210, secondary):** rather than hand-rolling a training pipeline in `ml/vision`
  from scratch under deadline pressure, use EI's transfer-learning object detection with INT8 quantization,
  trained on public wildlife/elephant datasets plus night-augmentation. Export a quantized TFLite model
  that runs on the QRB2210 (Adreno/OpenCL path if the runtime supports it, plain TFLite as fallback).
- **Acoustic corroboration (INMP441, stretch):** EI's audio classification block (MFCC + classifier) for
  the gunshot/chainsaw anti-poaching signal — same account, marginal extra setup cost once the pipeline
  exists for footfall.

One EI account training all three models for three different compute targets (MCU TinyML, Linux INT8
vision, Linux audio classifier) is also a genuine, honestly-earned "innovation" talking point for judging
— it's a real unified pipeline, not a gimmick bolted on for the story.

## 2. Where Arduino App Lab fits

App Lab is the pre-installed dev environment on UNO Q that combines an Arduino C++ sketch (STM32U585
side) with a Python app (QRB2210 Linux side) and a built-in inter-processor bridge. This is the concrete
implementation of CONTEXT.md §5's abstract "Bridge (RPC)" layer — use App Lab's native bridge primitive
instead of hand-rolling a UART/SPI framing protocol. Per `PROJECT_BLUEPRINT.md` §3 ("interfaces are
contracts"), define the RPC message schema first — MCU→MPU (features/events: footfall probability, ADC
features, gunshot flag) and MPU→MCU (decisions/commands: deterrence action, gain level, LED pattern) —
then implement both sides against that shared schema. Day 1 below includes a deliberate "hello world"
round-trip test through App Lab's bridge before any real content is built on top of it, specifically to
de-risk unfamiliar tooling early rather than discovering integration problems on day 10.

Using App Lab and Edge Impulse well also directly serves the Hackster contest's spirit — Arduino,
Qualcomm, and Edge Impulse are its three named sponsors, so a project that genuinely exercises all three
sponsor tools (not just the UNO Q board itself) reads as fuller use of what was provided.

## 3. Contest requirements, verified from primary sources (not search snippets)

**Robu / Arduino Physical AI Challenge India 2026** — confirmed live on the official contest page.
Deadline **23 Aug 2026**, registration by **15 Aug**, winners announced **31 Aug**. Team size 1–4, India
residents only, original/unpublished work. Judging (100 pts): Functionality & Execution **40**, Innovation
& Originality **25**, Technical Documentation **20**, Presentation & Creativity **15**. Submission needs: demo
video, GitHub source, project report PDF, mandatory UNO Q purchase proof.

**Hackster "Invent the Future with Arduino UNO Q and App Lab"** — confirmed from the official rules page.
Runs 3 Mar – **30 Aug 2026, 11:59 PM PT**, winners announced 25 Sep. Entries are single-Hackster-account
authored (not team-attributed on the platform itself). Judging (100 pts): Project Documentation/
Story-Instructions **30**, Complete BOM **20**, Schematics **15**, Code & Contribution **15**, Creativity **20**.
Submission needs project name, description, cover image, BOM, full instructions, images, and resource
files (schematics/code/CAD).

**One real content-policy risk to design the write-up around:** Hackster's rules explicitly bar content
involving "military, defense, autonomous weapons, harmful surveillance technologies." EleTect X's
anti-poaching gunshot/chainsaw corroboration (INMP441) is legitimate wildlife-conservation acoustic
classification, not surveillance of people, but the documentation must frame it that way explicitly —
"acoustic signature classification for a ranger alert," not "detecting humans" or "weapon detection." Bake
this framing into the project story from the first draft, not as a late edit.

## 4. Day-by-day schedule, Sun 26 Jul → Sat 8 Aug

| Date | Firmware (STM32U585) | Cognition (QRB2210) + ML | Hardware/integration | Exit criteria |
|---|---|---|---|---|
| **Sun 26 Jul** | Scaffold `device/mcu` (Arduino Core project, state-machine skeleton, power stub) | Define Bridge RPC schema (MCU→MPU features/events, MPU→MCU decisions); create 3 Edge Impulse projects (footfall, vision, acoustic) | — | Schema written down; EI projects exist; MCU project builds empty |
| **Mon 27 Jul** | Geophone ADC front-end (ADS1115+INA333 bench stand-in) + STA/LTA algorithm | Start collecting/labeling seismic training windows (bench stomp-tests + synthetic + public proxy data) | — | STA/LTA runs on bench data, logs trigger events |
| **Tue 28 Jul** | Actuator drivers (horn PWM gain-limited per ADR 0003, LED strobe, IR MOSFET pulse); LoRa MAC via Grove E5 | Scaffold `device/mpu` module tree; App Lab "hello world" round-trip MCU↔MPU | — | A dummy message survives a round trip through the real Bridge |
| **Wed 29 Jul** | Integrate EI footfall v1 model (C++ export) into STA/LTA pipeline; bench stomp-test | Vision capture (V4L2) skeleton on USB webcam stand-in; build EI vision dataset (public wildlife images + night augmentation) | — | Footfall model fires correctly on real stomp tests |
| **Thu 30 Jul** | Safety rule-gates: burst-duration cap + trigger cooldown (ADR 0003), unit-tested | Train EI vision v1 (INT8), export, run inference loop on QRB2210 against webcam stand-in | — | Vision detector returns confidence scores on stand-in feed |
| **Fri 31 Jul** | — | Implement log-odds fusion math (CONTEXT.md §4) fed by real STM32 features over the Bridge | — | Bench test: stomp + webcam trigger → fusion → risk score (detect+alert only, no deterrence yet) |
| **Sat 1 Aug** | Wire actuator commands from MPU decisions over the Bridge | Contextual bandit (never-repeat, stop-on-retreat) + SQLite experience store | — | **Milestone: full detect→confirm→deter→learn loop on bench with stand-ins (seismic + vision only — acoustic deferred, see ADR 0007 addendum)** |
| **Sun 2 Aug** | Swap in real actuators as parts arrive | Recalibrate thresholds on real sensor data | Real SM-24 geophone (potted capsule/spike — this is the scheduled Aug 2 reminder), real IMX462+940nm IR, real LEDs if arrived | Real-part swap validated against bench baseline |
| **Mon 3 Aug** | Power/load-switch management against real rail | — | 4S LiFePO4 + MPPT + solar + supercap + surge/reverse-polarity protection wired (scheduled Aug 3 reminder) | Power draw measured against µA-idle target |
| **Tue 4 Aug** | — | LoRa end-to-end: SenseCAP gateway (IN865 confirmed) → ChirpStack → `web/ingest` → Supabase → dashboard | Enclosure assembly starts: PETG print, gasket seams, e-PTFE vent, SUH-15 flush-mounted (ADR 0003), conformal coating | A real LoRa event shows up live on the already-built dashboard |
| **Wed 5 Aug** | — | — | Full closed-enclosure bench validation: sealed node, on battery/solar, triggers end-to-end | Sealed node runs unattended and reports correctly |
| **Thu 6 Aug** | Edge-case hardening: false-trigger rejection (wind/rain/vehicle), LoRa dropout/retry, battery-low safe state | Same hardening pass on cognition side | Multi-hour reliability soak test | No false triggers or crashes over the soak window |
| **Fri 7 Aug** | Flash/duplicate config for a spare node | — | Build the spare node (risk mitigation from the old plan) | Second unit flashable in minutes, not hours |
| **Sat 8 Aug** | **MVP freeze — bug fixes only past this point** | Final full-pipeline regression test | Tag a git release; node packed for transport | Node ready to leave for Kothamangalam |

Documentation runs in parallel throughout, not bolted on at the end: keep updating ADRs as decisions get
made, and start drafting the Robu project report and Hackster project story skeletons around **Aug 6–7**,
since documentation is worth 20–30% of either score and both docs benefit from being written while details
are fresh rather than reconstructed afterward.

## 5. After the freeze

- **~9–14 Aug — DFO field test (Kothamangalam):** deploy at a real crossing, detection+alert mode first,
  then capped deterrence per ADR 0003's cooldown/burst-cap safeguards. Capture night IR footage, power
  trace, and the bandit's learning curve. Iterate on anything the field exposes that the bench didn't. Get
  DFO sign-off/quote. **Single node, seismic + vision only** — acoustic is deferred (ADR 0007 addendum,
  30 Jul), so the field-bound unit isn't carrying that subsystem into this test.
- **~15 Aug onward — acoustic subsystem, on the second UNO Q unit:** INMP441 hardware bring-up, the
  ADR 0009 Rung 2 LPBAM dual-channel concurrency bench test, gunshot/chainsaw/vehicle/animal-call
  dataset collection (`DEVICE_DEVELOPMENT_WORKFLOW.md` §4a), and Edge Impulse acoustic model training —
  on the bench/dev unit, never touching the field-validated node. Runs alongside the submission sprints
  below, not blocking either.
- **15–23 Aug — Robu submission sprint:** register by 15 Aug. Cut the demo video (bench + field footage),
  finalize the GitHub repo (history already reads clean per the existing commit log), write the project
  report PDF mapped explicitly onto the four judged categories, attach UNO Q purchase proof, submit by 23
  Aug.
- **24–30 Aug — Hackster expansion sprint:** re-platform onto Hackster's project format under one
  authoring account. Add drawn/photographed schematics (15 pts — not yet started, needs its own time
  block). Adapt `hardware/bom/bom.md` into Hackster's BOM format (20 pts — mostly a repackaging job, not new
  work). Write the story/instructions to the "would a beginner reading this recreate it" bar (30 pts).
  Foreground genuinely creative technical choices for the Creativity score (20 pts): the felid-growl/
  bee-buzz deterrence research behind the audio design, the log-odds fusion math, the never-repeat bandit,
  and the one-account-three-targets Edge Impulse pipeline. Apply the conservation-not-surveillance framing
  from §3 throughout. Submit by 30 Aug.

## 6. Risk register

- **Hardware ordering closed 28 Jul.** Mechanical BOM, LED integration parts, and the power system
  (4S LiFePO4 pack w/ built-in BMS, LiFePO4-aware MPPT controller, 20 W panel) are all ordered; only the
  Steko lens (dropped, see §0 below) had a slow-shipping item. Remaining arrival risk is shipping time, not
  sourcing uncertainty — the geophone/camera/LED real-part swap dates in §4 may still slip a few days, but
  every software/ML task through 1 Aug already runs on bench stand-ins (ADS1115+INA333, USB webcam)
  validated as adequate, so the 8 Aug freeze doesn't depend on that slipping schedule resolving early.
- **Three trained models in ~10 days is genuinely aggressive**, vision especially. Mitigation: use existing
  public wildlife/camera-trap datasets rather than collecting original imagery, and keep the vision
  detector's scope narrow (elephant / not-elephant, plus a small number of secondary classes) rather than
  a broad multi-species classifier.
- **App Lab's Bridge is unfamiliar tooling.** Mitigation: Day 3's deliberate "hello world" round-trip test
  exists specifically to surface integration problems on day 3, not day 10.
- **The Resend transactional-email domain decision is still open** and matters for real residents signing
  up with real contact info, but it doesn't block either contest submission or the physical build — track
  it as a parallel item to close before real onboarding, not before 8 Aug.
- **Hackster's single-account-authorship rule** — confirm now which one account is the submitting author if
  more than one person is involved in the build, so this isn't a last-minute question on 29 Aug.

## 7. Division of labor

This Cowork session continues to plan, research, cross-check sourcing/specs, and verify (this document,
the ADRs, contest-rubric mapping). The local VS Code Claude Code session — with real repo/git/network/
Supabase/Vercel access — writes the actual firmware, Python cognition code, and Edge Impulse integration
day by day against this schedule; relay each day's prompt and status both ways. Physical work no agent can
perform — soldering, potting the geophone capsule, 3D-printing and gasketing the enclosure, the actual
field install — stays with you, along with the judgment calls on Edge Impulse dataset labeling that
benefit from a human in the loop.

## 8. Status as of 28 Jul — catch-up plan + the Opus/Sonnet handoff protocol

A repo scan run today confirms `device/mcu`, `device/mpu`, and `ml` are **still 100% `.gitkeep`/README
scaffolding** — none of Day 1 (Sun 26), Day 2 (Mon 27), or Day 3 (Tue 28)'s tasks have landed yet. That's
3 of 13 days gone with zero firmware/cognition code written. This isn't a reason to panic-replan; it's a
reason to compress the first three rows into one focused build pass, since nothing in those rows was
actually blocking on hardware or on each other — and to fix the process gap that let 3 days pass without
code: every session from here forward has a scoped, checkable exit condition (below), not an open-ended
"work on the firmware" prompt.

**Enclosure/LED decision closed since this doc was written:** the Steko lens+holder is dropped (ADR-worthy
— add one). The concept doc's own side-wing design never called for an optic; LEDs mount as bare
star-PCBs bonded via thermal adhesive straight into a printed heatsink-puck pocket in each wing. One fewer
part, one fewer slow-shipping dependency, and it better matches the wide-angle peripheral-deterrence intent
in `hardware/cad/enclosure-design-concept.md` than a focused 60° beam would have.

**All engineering conventions below are governed by `docs/ENGINEERING_CONVENTIONS.md`** — read it before
opening the first VS Code session. It fixes the layering, testing, and documentation bar; this section
only fixes *sequencing and session scoping*.

### Catch-up pass — today, compressed Day 1–3 scope in one sitting

Run as **one Opus planning call, then one or two Sonnet build calls**, not day-by-day:

1. **Opus (single call):** produce `device/mpu/bridge/schema.md` — the full Bridge RPC schema (MCU→MPU:
   footfall probability, raw ADC feature vector, gunshot flag; MPU→MCU: deterrence action, gain level, LED
   pattern), each field named/typed/ordered, version byte included (§6 of ENGINEERING_CONVENTIONS.md).
   Also produce the function-signature spec for the geophone bench front-end and the actuator drivers
   (`read_seismic_window()`, `read_acoustic_window()`, `drive_horn()`, `drive_led()`, `pulse_ir()`) — no
   implementation, just contracts + one-line pre/post/error behavior each. Output should be under two
   pages; if it's longer, it's drifted into implementation.
2. **Sonnet (build call 1 — `device/mcu`):** scaffold the Arduino Core project against the spec above:
   `config.h`, `state_machine.cpp` (skeleton), `sensors/geophone.cpp` (ADS1115+INA333 stand-in
   implementation of the contract), `footfall/sta_lta.cpp` (pure function, unit-tested with a synthetic
   trace — known-answer test per §4), `actuators/{horn,led,ir}.cpp`, `lora/mac.cpp` (Grove E5 AT join).
   **Exit condition:** `pio test` green on the STA/LTA unit test; `pio run` builds clean; a bench stomp-test
   produces a logged trigger event.
3. **Sonnet (build call 2 — `device/mpu` + Edge Impulse projects):** scaffold `device/mpu`'s module tree
   (`bridge/rpc.py` implementing the schema from step 1, `perception/`, `cognition/`, `services/config.py`),
   create the 3 Edge Impulse projects (footfall, vision, acoustic — empty/initialized, not trained yet), and
   run the App Lab "hello world" round-trip through the real Bridge. **Exit condition:** a dummy message
   sent from the MCU side is received and logged on the MPU side through App Lab's actual bridge, not a
   mock.

That closes Days 1–3's scope. Days 4 onward (Wed 29 Jul in §4's table — EI footfall model integration,
vision capture skeleton) resume the original day-by-day cadence from `BUILD_BLUEPRINT_AUG8.md` §4 as
written, one Sonnet session per row, each scoped to that row's exit criteria only.

### The standing protocol for every session after today

- **One Opus call per module boundary**, not per day: whenever a new interface needs defining (fusion's
  input/output contract, the bandit's state/action/reward shapes, the SQLite experience-store schema) —
  spec only, a page or less, no code.
- **One Sonnet call per schedule row**, scoped exactly to that row's "Exit criteria" cell in §4's table.
  Paste: `CONTEXT.md` relevant section, the specific Opus spec for the module in play, and the
  `ENGINEERING_CONVENTIONS.md` sections that apply (usually §2–4) — never the whole repo.
- **Every session ends with either a green test or an explicit blocker note in `KNOWN_GAPS.md`** — never a
  silent "mostly working." If a row's exit condition isn't met, the next session starts by fixing that row,
  not by moving to the next one.
- **You review the diff before it's committed**, every time — this is the one step no agent call replaces.

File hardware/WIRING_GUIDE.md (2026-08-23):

# EleTect X — physical wiring guide (bench bring-up, pre-battery)

Written 22 Aug 2026. Covers everything except the battery pack (Robu order #3636219, not yet
landed — see `hardware/bom/procurement-status.md`). Geophone and LoRa are already wired; this
guide is for the five subsystems still at **U** (unwired) in
`hardware/references/UNO_Q_PINOUT_REFERENCE.md`'s wiring-status table: horn, LED white, LED blue,
IR illuminator, and the shared power bus that feeds them.

Every pin assignment and constant below is quoted directly from `device/mcu/src/config.h` (line
numbers as of this writing) and the cited ADRs/BOM — nothing here is invented. Re-check `config.h`
directly if you're reading this more than a session or two after 22 Aug in case a value changed.

## 0. What's already done — don't re-wire this

| Subsystem | Status | Reference |
|---|---|---|
| Geophone (SM-24 → 1kΩ damping → INA333 → ADS1115 → D20/D21 I2C2) | **W** | `device/mcu/README.md`'s wiring table |
| Grove LoRa-E5 (Yellow=TX→D0, White=RX→D1, Red=VCC→5V, Black=GND→GND) | **P** — physically wired, module not yet answering AT probes (separate open issue, not a wiring defect) | `docs/KNOWN_GAPS.md`'s 18 Aug entry |
| Camera (Arducam IMX462 → USB hub/adapter → UNO Q USB-C) | Bench-verified, no new wiring needed | `docs/KNOWN_GAPS.md`, build-call 3 |

## 1. Power bus — the part that doesn't need the battery to build

Wire the whole bus now; leave the battery-side leads unterminated (twist-capped or in a spare
WAGO port) until the pack lands. Everything downstream of the bus can be fully built and even
bench-powered from a substitute source today (§1c).

**Topology** (per `hardware/bom/procurement-status.md`'s own power-switch row, "battery+ → fuse →
switch → WAGO splice point → branches"):

```
Battery+ (4S LiFePO4, 12.8V nominal) → 6A blade fuse → SPST switch → WAGO 5-way splice → branches:
  1. UNO Q VIN (7-24VDC input, onboard LMR51440 bucks to 5V — confirmed via official Arduino
     power spec, procurement-status.md §Buck audit)
  2. TPA3116D2 amp DC input (XH-M543 board, rated 12-24VDC per its listing — wired straight to
     the bus, no buck needed, same audit)
  3. LED buck driver #1 input (→ cool-white LED string)
  4. LED buck driver #2 input (→ royal-blue LED string)
  5. IR illuminator's own XL4015 buck input (steps 12.8-14.6V down to the board's fixed 12V
     rating — required, see §4)
Battery− → common ground bus (WAGO or bus bar) → all of the above returns.
```

**Not on this bus: the DFPlayer PRO.** Per its own spec sheet it runs on 3.3-5V, not the 12.8V
actuator bus. Tap its VIN off the UNO Q's 5V pin instead (same rail the LoRa E5's VCC already
uses), GND to common ground. See §3 step 2.

**1a. Fuse and switch.** Both are local-store items per `procurement-status.md` — 6A blade fuse
(revised up from 5A on 14 Aug because 5A's margin over the 45.1W worst-case peak shrinks to 1.11x
at low battery voltage), SPST 2-position ON/OFF rated ≥10A/12V DC. Wire fuse and switch in series
on the **positive** leg only, between battery+ and the WAGO splice — never fuse/switch the ground
return.

**1b. Wire gauge for the bus.** System peak draw is already computed in `procurement-status.md`:
**3.52A at nominal 12.8V, rising to 4.51A at a depleted ~10V pack** (that 45.1W worst-case figure
divided by voltage). Sized against a real automotive 12V ampacity chart (2% voltage-drop
convention, [WiringProducts' automotive wire chart](https://wiringproducts.com/pages/wire-amperage-capacity-chart)):
16AWG carries 5A comfortably out to 11.5ft, 10A out to 5.8ft. Your run inside one small enclosure
is under 1ft in every case, so gauge choice here is about safety margin and connector fit, not
voltage drop.

Use what's already in hand (`procurement-status.md`'s "Already in hand" list) — no new wire
purchase needed:
- **16AWG silicone wire** — main bus: battery+ → fuse → switch → WAGO, and WAGO → each branch's
  first few inches before it steps down to a lighter gauge at the load itself. This is your
  heaviest stock and the right choice for the only run carrying the full system current.
- **18AWG PTFE (red+black)** — branch feeds to the TPA3116D2 amp's DC input and to each XL4015
  buck driver's input side (LED bucks, IR buck) — each of these branches carries at most ~1A,
  18AWG has enormous margin.
- **22AWG 2-core** — buck driver *output* → LED string, and IR buck output → IR board (each ≤0.3A,
  see §4/§5).
- **XT30UD pair** (2 in hand) — good fit for the battery-to-fuse or fuse-to-switch joint if you
  want a disconnectable bench connector there rather than a permanent solder/crimp joint;
  otherwise WAGO levers throughout are simpler and already specified.
- **WAGO lever splice connectors (2/3/5-way, in hand)** — use the 5-way at the main splice point
  exactly as `procurement-status.md` specifies.

**1c. Real battery in hand (22 Aug) — first-use checklist before it touches anything.** The Robu
Pro-Range IFR 32650 12.8V 6000mAh 4S1P LiFePO4 pack has arrived
(`hardware/bom/procurement-status.md`). Before it connects to the bus for the first time:

1. **Multimeter the resting voltage before touching anything else.** A healthy 4S LiFePO4 pack
   rests somewhere in the 12.8-13.6V range depending on state of charge — it should not read near
   0V (dead/miswired BMS) or above ~14.6V (over-charged, do not use). If it reads outside a sane
   range, stop and don't connect it.
2. **Confirm polarity at the XT30 connector before plugging in** — reversed polarity on a LiFePO4
   pack is a real fire risk, not just a "won't work" mistake. The XT30UD pairs already in hand are
   keyed, but verify with the multimeter anyway; don't trust the connector shape alone on a
   first-ever connection.
3. **No fuse/switch yet, and this is now the real pack, not a current-limited bench supply** — a
   short on this bus can deliver far more fault current than a wall adapter ever would, limited
   mainly by the BMS's own trip threshold and the battery's internal resistance, not by anything
   you've wired. Getting the ₹100-150 fuse+switch before this pack goes anywhere near the actuator
   bus is a stronger recommendation now than it was with a bench supply — if a local store is
   reachable before you wire further, that's the highest-leverage five minutes available tonight.
   If it genuinely isn't reachable in time: keep every connection brief and supervised, verify each
   new branch with the multimeter before power-on, disconnect the battery between stages rather
   than leaving it hot while you wire the next one, and never leave it connected unattended.
4. **Charging setup (XL4015 set to 14.2V CC/CV) is a separate task from tonight's bring-up** — the
   pack should already carry enough charge to bench-test the actuators directly off it; don't wire
   up the solar/charge path tonight unless you specifically want to. Keep that XL4015 distinct from
   the two load-side XL4015 bucks (LED, IR) — three total XL4015 modules in this system, easy to
   mix up.

Do **not** substitute the UNO Q's own USB-C port for the 12.8V actuator bus — USB-C powers the
board itself only (5V rail); it isn't wired to backfeed the actuator bus and isn't safe to attempt.

## 2. GPIO control-signal wiring (D2/D3/D4/D5/D6/D7/D8)

These are logic-level signal wires, not power — the UNO Q's own thin jumper wire or the 26AWG
stock in hand is correct here, not the heavier bus gauges above. All pins below are confirmed
5V-tolerant on input per `hardware/references/UNO_Q_PINOUT_REFERENCE.md`'s official warning
("all MCU GPIOs are 3.3V logic and 5V tolerant, except A0 and A1") — relevant below because the
IRLZ44N gate side taps in at 3.3V, not 5V.

| Pin | MCU pin | `config.h` name | Drives |
|---|---|---|---|
| D2 | PB3 | `AUDIO_TRIGGER_PIN` | DFPlayer IO/ADKEY input (§3) |
| D4 | PA12 | `HORN_AMP_ENABLE_PIN` | TPA3116D2 `SHUTDOWN` pin, active-low (§3) |
| D5 | PA11 | `LED_WHITE_PIN` (→ **planned rename `LED_WHITE_LEFT_PIN`**, §4) | IRLZ44N gate, white LED branch, left wing (§4) |
| D3 | PB0 | **planned `LED_WHITE_RIGHT_PIN`** — not yet in `config.h`, confirmed free/unused, PWM-capable (OPAMP2 output shares this pin but is unused in this design) | IRLZ44N gate, white LED branch, right wing (§4) |
| D6 | PB1 | `LED_BLUE_PIN` (→ **planned rename `LED_BLUE_LEFT_PIN`**, §4) | IRLZ44N gate, blue LED branch, left wing (§4) |
| D8 | PB4 | **planned `LED_BLUE_RIGHT_PIN`** — not yet in `config.h`, confirmed free/unused | IRLZ44N gate, blue LED branch, right wing (§4) |
| D7 | PB2 | `IR_ILLUMINATOR_PIN` | IRLZ44N (or LR7843 module) gate, IR board (§5) |

**D3/D8 are a planned addition, not yet in firmware — see §4.0.** Don't wire them expecting
`led.cpp` to already drive them; `config.h`/`led.cpp`/`led.h` need the corresponding update first
(next VS Code/Sonnet session), same one-at-a-time Bridge-registration discipline as every other
actuator pin in this repo.

## 3. Horn: DFPlayer PRO → TPA3116D2 (XH-M543) → Ahuja SUH-15

Per ADR 0003 (single BTL channel, not PBTL) and ADR 0011 (SUH-15 now lives in its own small IP66
housing, off the main enclosure, connected by 2-core speaker wire through a gasketed gland).
Revised 22 Aug against the real DFPlayer PRO (DFR0768) datasheet/schematic and the actual
techtonics XH-M543 board photos — three corrections from the original plan, all verified against
primary sources, not assumed:

1. **DFPlayer PRO power: VIN → UNO Q 5V, GND → common ground.** Its spec sheet states 3.3-5V —
   it does **not** go on the 12.8V actuator bus (see §1's new note). Confirm with a multimeter
   before connecting.
2. **D2 (`AUDIO_TRIGGER_PIN`, PB3) → DFPlayer PRO's `KEY` pin, active-low.** This is the DFR0768's
   real pin name — "IO/ADKEY" was the DFPlayer *Mini*'s naming, different hardware. The DF1101S
   chip inside the PRO pulls `KEY` up to its own IO rail through a 22kΩ resistor (idle **high**)
   and reads a direct short to ground as key K1 = Play & Pause (confirmed in the DF1101S
   datasheet §5 and cross-checked against a DFRobot reference schematic for a sibling board using
   the same chip). `horn.cpp` was fixed 22 Aug (commit `493f2fb`) to idle `AUDIO_TRIGGER_PIN` high
   and pulse it low — matches this circuit now. A direct jumper from D2 to `KEY` is correct, no
   resistor needed (K1's own series resistance is 0Ω).
3. **DFPlayer PRO's `DACL` pin → amp's `INL` terminal; DFPlayer `GND` → amp `GND`** (the 3-pin
   `VOL_L | INL GND INR | VOL_R` input block on the XH-M543 board). **Do not use the DFPlayer's
   `L+`/`L-`/`R+`/`R-` pins here** — those are its own built-in speaker-level BTL output, meant to
   drive a bare speaker directly, not to feed another amp's line input; wiring them into `INL`
   would mismatch both signal level and topology. `DACL` is the chip's actual line-level DAC
   output (1Vrms swing per the DF1101S datasheet §3.4) — the correct signal for this path.
4. **No hardware shutdown/mute pin exists on this board.** The techtonics XH-M543 listing (₹289,
   the one actually in hand) and its product photos confirm the only terminals are: power in
   (`VCC`/`GND`), the 3-pin audio input above, two speaker outputs (`L`, `R`), and two volume
   trimpots (`VOL_L`, `VOL_R`). `config.h`'s `HORN_AMP_ENABLE_PIN` comment assumed a `SHUTDOWN`
   pin that this specific board doesn't expose. **Fallback: D4 (`HORN_AMP_ENABLE_PIN`, PA12) →
   IRLZ44N gate (or the LR7843 module), switching the amp's `VCC` line** — same 220-330Ω series
   gate resistor + 10kΩ pulldown pattern as §4/§5's LED and IR MOSFETs. This is power-side
   enable/disable instead of an IC mute pin, but functionally the same gate that
   `HORN_AMP_ENABLE_DELAY_MS` (150ms, still an invented placeholder per `docs/KNOWN_GAPS.md`)
   times against.
5. **Amp output (`L+`/`L-` on the XH-M543, the channel wired to `INL`) → Ahuja SUH-15 (8Ω)**, via
   2-core speaker wire through the gasketed gland into the horn's separate housing (ADR 0011).
   16-18AWG stock in hand is fine for the ~1A the amp draws at its software-limited 6-8W output.
6. **Amp `VCC`/`GND` → the IRLZ44N switch from step 4 → power bus** (§1). No buck needed — this
   board's spec (12-24V range, 2×50W at 12V) covers the 12.8-14.6V range with margin.

**Volume control — better news than originally thought.** The XH-M543's `VOL_L` trimpot sits
*after* the DFPlayer in the signal chain, so it's a real physical gain stage independent of
whatever volume the DFPlayer itself is set to — unlike a pure DFPlayer-only setup, you're not
purely at the mercy of an unknown value baked into the module's flash. **Turn `VOL_L` fully
counterclockwise (minimum) before first power-on**, trigger a test play, and bring it up
gradually while listening, rather than assuming any starting position is safe.

## 4. LED deterrence: cool-white + royal-blue via IRLZ44N

**4.0 Redesign decided 22 Aug (Cowork planning session) — supersedes the ×4/×2, 2-channel plan
below wherever it conflicts. Not yet reflected in `config.h`/`led.cpp`/`led.h`.**

Real constraint discovered same night: only 10 heatsink pucks in hand, against a much larger bare-LED
stock. Decision, reasoned from deterrence effectiveness / practicality / power (not from enclosure
CAD, which is not fixed):

- **10 LEDs total, all heatsinked (never run a 3W star bare — real field-reliability risk over a
  multi-day trial): 6 cool-white + 4 royal-blue.** Ratio 1.5:1, not the original BOM's 2:1 — still
  white-leaning (cool-white's phosphor hump overlaps the ~496nm rod peak most large-mammal targets
  use at night better than narrow royal-blue does) while keeping blue meaningfully present (hedges
  the ~30% non-nocturnal encounters, and doubles as spectral-diversity insurance against exact
  photoreceptor-tuning uncertainty).
- **4 independent channels, not 2**: white-left / white-right / blue-left / blue-right. Each color
  still has exactly one buck (2 bucks total, unchanged from the original BOM, already in hand) —
  the buck output splits into two matched parallel branches (left wing, right wing), each gated by
  its own IRLZ44N. White = 3 branches of 2-LEDs-in-series (2 on one wing's switch, 1 on the
  other's — see below); blue = 2 branches of 2-LEDs-in-series (1 per wing). Branches within one
  color are always 2-in-series, sized against the buck's dropout margin at a depleted ~10V pack —
  do not run 3 in series per branch, that's the real ceiling, not an arbitrary one.
- **Why 4 channels, not 2:** the actual evidence-backed deterrence lever is unpredictability, not
  raw brightness — real field literature on flashing-light deterrents (coyote/sheep strobe-siren
  trials, FoxLights, and a directly-relevant finding that elk/deer habituate fast to *stationary*
  deterrents) says varying pattern and color prevents habituation; a static "both wings, both
  colors, every time" burst does not. 4 independent channels let `led.cpp`/the bandit layer
  actually alternate side and color across triggers instead of firing identically every time.
  `ALERT_LED_PATTERN_ID` (already a placeholder in the MPU cognition layer, currently unwired) is
  the natural hook for this — implementing real pattern logic there is higher-value than any
  further LED-count increase.
- **Power/fuse check, real and not yet done — do this before wiring 10 LEDs:** 10 LEDs at ~2.24W
  each (700mA × ~3.2V typical for a 3W star) is ~22.4W if every LED fired simultaneously, versus
  ~13.4W for the original 6-LED plan the existing 6A fuse was sized against
  (`hardware/bom/procurement-status.md`'s 45.1W worst-case-peak / 1.11x-margin calculation). That's
  roughly +9W on top of the system's worst-case simultaneous peak (horn + LED + IR all firing at
  the top deterrence tier). **Re-run that worst-case-peak arithmetic with 10 LEDs before wiring
  them** and confirm the 6A fuse still clears the project's own 1.25x safety convention at a
  depleted pack — if not, it's a cheap fuse-rating bump, not a redesign, but it must be checked,
  not assumed.
- **Firmware work needed before this is real** (next VS Code/Sonnet session, one-at-a-time Bridge
  discipline as always): add `LED_WHITE_RIGHT_PIN`/`LED_BLUE_RIGHT_PIN` to `config.h` (D3/D8, both
  confirmed free), extend `led_channel` in `led.h` from `{kWhite, kBlue}` to 4 values (or a
  color×side pair), extend `led.cpp`'s `channel_state` array from 2 to 4 instances, and update
  `bridge_handlers.cpp`/`schema.md`'s `drive_led` channel field to address 4 channels. None of this
  is wired live yet — same commented-out-`Bridge.provide()` discipline applies to any new
  registration.

Everything below (buck sizing, MOSFET gate pattern, wire gauge) is unchanged and still correct —
only the channel count and per-branch LED count change. Read it per-branch: wherever it says "the
LED string," that's now "one 2-LED-in-series branch," repeated 3× for white and 2× for blue.

**Per color channel** (repeat for white and blue, using D5/D6 respectively):

1. **XL4015 buck driver, battery bus → LED string.** Set the buck's output voltage/current to
   match the LED string's forward-voltage/current spec (wire the LEDs in the series/parallel
   configuration your buck driver's rated output current supports — a 3W LED typically runs
   ~700mA at ~3.2-3.4V forward voltage; check the actual star datasheet you received before
   setting the trimmer, since "3W" alone doesn't fix the exact Vf/If). Mount each LED star on a
   heatsink puck with thermal adhesive tape — these get genuinely warm at 700mA and the puck is
   there for a reason, don't skip it.
2. **IRLZ44N as a low-side switch between the LED string's return and ground.** IRLZ44N is a real
   logic-level MOSFET — datasheet-confirmed gate threshold `Vgs(th)` ≈1-2V, and it's specifically
   designed for direct low-voltage gate drive (down to and below 5V) rather than the ~10V a
   standard power MOSFET needs. At the UNO Q's 3.3V GPIO drive it's fully in logic-level territory
   and will switch cleanly at these LED currents (≤~1.4A per channel across 2 LEDs) — `Rds(on)`
   at 3.3-5V gate drive is in the tens-of-milliohms range per the datasheet, negligible heating at
   this current. ([IRLZ44N datasheet, thierry-lequeu.fr mirror](https://www.thierry-lequeu.fr/data/IRLZ44N.pdf))
   Wiring: LED string cathode → MOSFET drain; MOSFET source → ground bus; MOSFET gate ← D5 (or D6)
   through a **220-330Ω series gate resistor** (standard practice, limits inrush into the gate
   capacitance — not in the BOM by name but any resistor from the existing kit in that range
   works) and a **10kΩ pulldown resistor from gate to source** (holds the LED firmly off during
   MCU boot/reset, before `led_init()` has run — without this, an undriven gate can float and
   flicker the LED on briefly at power-up).
3. **Buck driver output → LED string**: 22AWG 2-core is right for this run (≤1.4A per channel,
   well inside 22AWG's margin over a short in-enclosure run).

## 5. IR illuminator: 940nm board via its own XL4015 buck

Per the BOM's flagged finding (`procurement-status.md` §6 Buck/regulation audit): the VISTORA
48-LED IR board (ASIN B0H2DQ9DVK) states a **single fixed Input Voltage: DC12V** (not a range),
drawing 300mA — the battery bus's 14.6V absorption peak exceeds this by ~22%, a real overvoltage
risk to a board with no stated input tolerance margin. This is why one of the spare XL4015 bucks
is earmarked specifically for this board, set to output ~12V.

1. **Battery bus → dedicated XL4015 buck (set to 12V output, verified by multimeter before
   connecting the IR board)** → IR board's 12V input.
2. **D7 (`IR_ILLUMINATOR_PIN`, PB2) → gate of an IRLZ44N low-side switch** on the IR board's
   ground return, same gate-resistor + pulldown pattern as §4 — or use the **LR7843 module**
   already in hand (pre-built screw-terminal MOSFET switch) here instead of a bare IRLZ44N, since
   `procurement-status.md`'s own Flag #3 suggests this exact position as the best fit for it (it's
   a better match for the "no PCB fab" constraint than hand-wiring another bare IRLZ44N).
3. `IR_PULSE_MAX_MS` is 500ms with a 5s minimum interval (config.h lines 394-398) — sized to keep
   duty under 10% at max pulse width specifically to stay inside the gate MOSFET's thermal limit,
   per the comment in config.h. Nothing to wire differently for this, just worth knowing why those
   numbers are what they are before you consider changing them.

## 6. Before first power-on — checklist

1. Multimeter-verify the XL4015 buck outputs (main charge-path buck if wired, LED bucks, IR buck)
   **with no load connected**, before connecting anything downstream — this is the same discipline
   `procurement-status.md` already specifies for the charge-side XL4015.
2. Confirm fuse and switch are both in the positive leg only, ground bus is common and unfused.
3. Turn the XH-M543's `VOL_L` trimpot to minimum before the amp's MOSFET enable (D4/IRLZ44N) is
   ever switched on (§3) — it's the one real physical volume control in this signal path.
4. Confirm every IRLZ44N (or LR7843) gate has its pulldown resistor before power-on — an
   undriven/floating gate on a logic-level MOSFET can partially turn on unpredictably. This now
   includes the horn's amp-enable MOSFET (§3 step 4), not just the LED/IR channels.
5. Once everything above is wired and the bench power source (§1c) is connected: flash with
   `FIRE_TEST_HARNESS 1` (same procedure as the 22 Aug bare-board session,
   `docs/eletect-x-applab-notes.md`) and test each actuator with the `1`/`2`/`3`/`4` console
   commands — this is the fastest path from "wired" to "confirmed working," no new firmware
   needed. Watch/listen for each fire this time, since last session only had the console ack to
   go on.
6. Update `hardware/references/UNO_Q_PINOUT_REFERENCE.md`'s wiring-status table (D2/D4/D5/D6/D7
   from **U** to **W**) as each one is confirmed — keep that table current, same discipline it
   already documents for itself.

Sources: [IRLZ44N datasheet (thierry-lequeu.fr mirror)](https://www.thierry-lequeu.fr/data/IRLZ44N.pdf), [Automotive wire amperage capacity chart, WiringProducts](https://wiringproducts.com/pages/wire-amperage-capacity-chart)

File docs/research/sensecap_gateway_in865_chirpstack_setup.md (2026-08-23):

# SenseCAP M2 gateway: EU868 → IN865 + ChirpStack setup guide

- **Status:** research complete, hardware verification still needed
- **Date:** 2026-08-16
- **Author's note:** written from Seeed's official wiki/docs and two independent real-world
  IN865-in-India deployment write-ups (cited below), not from memory. One material gap remains
  open and is flagged clearly in §4 — do not skip it.

This closes the research portion of the open item in `HANDOVER.md` ("SenseCAP gateway is still
labeled EU868, must be set to IN865 region profile in ChirpStack and join-tested before any real
transmission") and the matching follow-up in ADR 0002 §Consequences. It does not close the item
outright — the actual gateway hasn't been touched yet, and §4 below is a real open question that
can only be resolved with the physical unit in hand.

## 1. Accessing the gateway's local console

Source: [Quick Start | Seeed Studio Wiki](https://wiki.seeedstudio.com/quick_start_with_M2_MP/),
confirmed by the official PDF
([Quick Start for SenseCAP M2 Gateway & Sensors](https://files.seeedstudio.com/products/SenseCAP/M2_Multi-Platform_Gateway/Quick%20Start%20for%20SenseCAP%20M2%20Gateway%20&%20Sensors.pdf)).

1. Power on: connect antenna + power adapter. Power LED is red at first, then the top indicator
   flashes green after ~15s once booted.
2. Enter configuration mode: press the physical button for 5 seconds until the blue indicator
   **flashes slowly**.
3. On your laptop/phone, join the Wi-Fi hotspot named **`SenseCAP_XXXXXX`** (XXXXXX = last 6
   hex digits of the device's MAC), password **`12345678`**.
4. Browse to **`192.168.168.1`**.
5. Log in with the username/password printed on the device's physical label (not a fixed
   default — check the label itself).

Alternative: connect the gateway to your router via Ethernet, find its DHCP-assigned IP on the
router's admin page, and browse to that IP instead of using the AP-hotspot method.

Gateway EUI: neither the Quick Start guide nor the Overview page states where it's displayed in
the local console UI. In practice it is almost always shown on the device's physical label and/or
under the same status/network page as the MAC address — confirm this once you're in the console;
you need it for step 2 of §3 below.

## 2. Setting the region/frequency plan to IN865

Source: [SenseCAP M2 MP Gateway LNS Configuration](https://wiki.seeedstudio.com/Network/SenseCAP_Network/SenseCAP_M2_Multi_Platform/SenseCAP_M2_MP_Gateway_LNS_Configuration/) and the
[ChirpStack tutorial](https://wiki.seeedstudio.com/Network/SenseCAP_Network/SenseCAP_M2_Multi_Platform/Tutorial/Connect-M2-Multi-Platform-Gateway-to-ChirpStack/) (both agree on this menu path).

1. In the local console, go to **`LoRa` → `Channel Plan`**.
2. "Select the Region and Frequency plan" (exact dropdown wording per the wiki) — pick the
   IN865 entry.
3. Click **`Save&Apply`**.

This is the one step ADR 0002 flags as required before any real transmission (868 MHz is illegal
to operate in India). **See §4 — whether IN865 actually appears in this dropdown on your specific
unit is not yet confirmed.**

## 3. Registering the gateway with ChirpStack

Source: [Connect M2 Multi-Platform Gateway to ChirpStack](https://wiki.seeedstudio.com/Network/SenseCAP_Network/SenseCAP_M2_Multi_Platform/Tutorial/Connect-M2-Multi-Platform-Gateway-to-ChirpStack/).

**On the ChirpStack side:**
1. Log into the ChirpStack web UI (default `admin`/`admin` if freshly installed — change this
   before going live).
2. **Gateways → Add gateway**: give it a name, enter the **Gateway EUI** (from the device label
   or local console, per §1).
3. **Device profile → Add device profile**: set Region to match IN865, **MAC version:
   LoRaWAN 1.0.3**, **Regional parameters revision: A**, **ADR algorithm: Default ADR algorithm
   (LoRa only)**.
4. **Application → Add Application** → Devices tab → **Add device**: enter device Name and
   **Device EUI** (from the device label or the SenseCAP Mate app), assign the device profile
   from step 3.

**On the gateway side**, in the local console:
1. Go to **`LoRa` → `LoRa Network`**.
2. Set **Mode: Packet Forward**.
3. **Gateway EUI** auto-populates.
4. **Server Address**: your ChirpStack server's address (LAN IP or hostname reachable from the
   gateway).
5. **Server Port (Up/Down): 1700** (standard Semtech UDP packet-forwarder port).
6. Click **`Save&Apply`**.

Note: the wiki's LNS-configuration page also documents a separate **`Mode: Local Network
Server`** option (MQTT broker fields — Broker Host/Port/User/Password) that runs a *local*
ChirpStack instance directly on the gateway itself. That's a different deployment model from
"gateway → Packet Forward → your own external ChirpStack server," which is what ADR 0002 already
specifies (§4/§5 of the ADR: "gateway is SenseCAP SX1302, region IN865, → ChirpStack" as a
separate LNS, not on-gateway). Use **Packet Forward mode** (steps above), not Local Network Server
mode, unless the architecture decision changes.

## 4. Open risk — not yet confirmed: does IN865 actually appear as a channel-plan option?

This is the one piece of real, previously-unflagged uncertainty this research surfaced, and it's
worth stating plainly rather than assuming the happy path:

- Seeed sells the SenseCAP M2 as **separate regional SKUs** — the product listing page shows
  a "Region" selector with **AU915, US915, AS923, AS923(Japan), EU868** as the purchasable
  variants ([Seeed product page](https://www.seeedstudio.com/SenseCAP-Multi-Platform-LoRaWAN-Indoor-Gateway-SX1302-EU868-p-5471.html)).
  **IN865 is not listed as a purchasable SKU.** The same page's spec sheet does say the radio
  "supports global LoRaWAN frequency plans from 865 MHz to 923 MHz," which technically covers
  865 MHz — but that's an RF-range claim, not a confirmation that "IN865" is a selectable
  named entry in the Channel Plan dropdown on an EU868-labeled unit.
- Two independent real-world write-ups exist of people deploying this exact gateway for IN865 in
  India, and **both started from EU868-labeled hardware, not an IN865 SKU**:
  - [SensCAP M2: IN865 LoRa Gateway, 4G-Ready Deployment (Hackster.io)](https://www.hackster.io/vinayyn/sensecap-m2-in865-lorawan-gateway-4g-ready-deployment-9f0da3)
  - [SenseCAP M2: IN865 LoRa Gateway Setup with 4G Backhaul (DFRobot community)](https://community.dfrobot.com/makelog-313793.html)
  
  Neither report describes hitting a wall where IN865 was missing from the Channel Plan
  dropdown, and neither reports a firmware swap or RMA to get IN865 working. That's a genuinely
  reassuring signal — it suggests the "EU868" in the product name is the as-shipped default
  channel plan, not a hard RF-hardware lock. But **neither write-up shows the actual dropdown
  contents or explicitly states "IN865 was there and I selected it"** — the ChirpStack
  tutorial's own instructions just say "select the Region and Frequency plan according to the
  actual choice" without listing the options. So this is corroborating evidence, not
  confirmation.

**Bottom line:** two real deployments strongly suggest this works, but nobody's write-up
explicitly confirms the dropdown contains an IN865 entry. The very first thing to do once the
gateway is powered on is open `LoRa → Channel Plan` and look — that single screenshot either
closes this gap for good or tells us early (before the contest/Aug 20 deadline, not after) that a
support ticket or firmware update is needed. Recommend this be the very first action on
unboxing, ahead of any ChirpStack wiring — it's a five-minute check that gates everything else
in this document.

## 5. Sources consulted

- [Quick Start | Seeed Studio Wiki](https://wiki.seeedstudio.com/quick_start_with_M2_MP/)
- [Quick Start for SenseCAP M2 Gateway & Sensors (PDF)](https://files.seeedstudio.com/products/SenseCAP/M2_Multi-Platform_Gateway/Quick%20Start%20for%20SenseCAP%20M2%20Gateway%20&%20Sensors.pdf)
- [SenseCAP M2 Multi-Platform Gateway Overview](https://wiki.seeedstudio.com/Network/SenseCAP_Network/SenseCAP_M2_Multi_Platform/SenseCAP_M2_Multi_Platform_Overview/)
- [SenseCAP M2 MP Gateway LNS Configuration](https://wiki.seeedstudio.com/Network/SenseCAP_Network/SenseCAP_M2_Multi_Platform/SenseCAP_M2_MP_Gateway_LNS_Configuration/)
- [Connect M2 Multi-Platform Gateway to ChirpStack](https://wiki.seeedstudio.com/Network/SenseCAP_Network/SenseCAP_M2_Multi_Platform/Tutorial/Connect-M2-Multi-Platform-Gateway-to-ChirpStack/)
- [traffic_saving_config (checked, not directly relevant — 4G data-usage feature, no region info)](https://wiki.seeedstudio.com/traffic_saving_config/)
- [Seeed product page: SenseCAP M2 SX1302 — EU868](https://www.seeedstudio.com/SenseCAP-Multi-Platform-LoRaWAN-Indoor-Gateway-SX1302-EU868-p-5471.html)
- [SenseCAP M2: IN865 LoRa Gateway, 4G-Ready Deployment (Hackster.io)](https://www.hackster.io/vinayyn/sensecap-m2-in865-lorawan-gateway-4g-ready-deployment-9f0da3)
- [SenseCAP M2: IN865 LoRa Gateway Setup with 4G Backhaul (DFRobot community)](https://community.dfrobot.com/makelog-313793.html)

Not used / not directly applicable to this frozen architecture (ADR 0002 names ChirpStack, not
these), but present in the URL list the user provided — noted here for completeness rather than
silently dropped:
- Connect M2 Multi-Platform Gateway to AWS IoT, to The Things Network — different LNS targets.
- Grove Wio-E5 TTN Demo, Helium Demo, Helium tinyML Demo, SenseCAP Cloud Demo, SenseCAP+XIAO
  ESP32S3 Demo — different network/cloud targets than this project's ChirpStack decision.
- Grove Wio-E5 P2P demo — useful in general (confirms `AT`/`+AT: OK`, `AT+MODE=TEST` command
  shape exists on this module family) but is raw point-to-point mode, not the OTAA/LoRaWAN join
  sequence `mac.cpp` needs — doesn't change anything in the pending mac.cpp fix prompt.
- Grove LoRa-E5 product page, `Grove_LoRa_E5_New_Version` wiki page — both explicitly defer to
  the official AT Command Specification PDF for exact command syntax rather than listing it
  inline; that PDF is the same one already fetched and used for the `mac.cpp` AT-command fix
  work in this session's earlier turn, so no new information here.

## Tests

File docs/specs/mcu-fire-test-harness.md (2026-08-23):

# Spec — MCU manual fire-test harness

Status: ready to build. Written by the planning session, 14 Aug, against the actual current state of
`device/mcu/src/` (not generic advice — every convention below is copied from code already in the repo).
Build exactly this; if something here conflicts with a file you're looking at, the real file wins and
the conflict should be logged in `docs/KNOWN_GAPS.md`, not silently resolved either way.

## Why this exists

`horn.cpp`, `led.cpp`, `ir.cpp` are real, complete drivers — nobody has fired any of them on real
hardware yet. Before any decision logic (fusion, bandit, Bridge wiring) gets layered on top, someone
needs to confirm the horn, LEDs, and IR illuminator physically switch on command. This harness is a
serial-command bench tool for exactly that: type a character in App Lab's Serial Monitor, one actuator
fires once, the full ack prints back. Nothing autonomous, nothing Bridge-registered — a human has to
type the command each time, which is the point: it cannot fire anything unattended.

## Scope boundary — read this before writing any code

This harness calls `drive_horn()`, `drive_led()`, `pulse_ir()` **directly as C++ functions**. It does
**not** touch `Bridge.provide()`. `docs/KNOWN_GAPS.md` and `device/mpu/bridge/rpc.py`'s module
docstring both document that Bridge registration for these three functions is deliberately deferred to
its own hardware session, one function at a time, because a past registration attempt broke every
previously-working Bridge function on the same sketch. Do not register anything with Bridge as part of
this feature. If that temptation comes up, stop and flag it instead.

## Files to add

Both files are new, flat in `device/mcu/src/` — per ADR 0010, `src/` has no subfolders and every file
sits at the same depth with plain `#include "whatever.h"`. Don't create a subfolder for this.

- `device/mcu/src/fire_test.h`
- `device/mcu/src/fire_test.cpp`
- `device/mcu/tests/test_fire_test/test_fire_test.cpp` (new test directory, mirrors `test_rule_gate/`)

## `fire_test.h` — public surface

```cpp
#ifndef FIRE_TEST_H
#define FIRE_TEST_H

#include <stdint.h>

// One serial-command byte maps to exactly one bench actuator target, or to
// no target at all. Pure function, no hardware calls, no side effects -
// this is the one piece of the harness that's host-testable without a
// board, same discipline as rule_gate.h's pure core (ENGINEERING_CONVENTIONS.md 4).
enum class fire_test_target { kNone, kHorn, kLedWhite, kLedBlue, kIr, kHelp };

fire_test_target fire_test_parse_command(char c);

void fire_test_init();
void fire_test_service(uint32_t now_ms);

#endif  // FIRE_TEST_H
```

## `fire_test.cpp` — behavior

Command map (single ASCII digit per actuator, kept deliberately unambiguous — no letter overlaps with
anything else the firmware prints or expects):

| Key | Target | Default request |
|---|---|---|
| `1` | Horn | `duration_ms=FIRE_TEST_HORN_DURATION_MS, gain_pct=FIRE_TEST_HORN_GAIN_PCT` |
| `2` | LED white | `duration_ms=FIRE_TEST_LED_DURATION_MS, gain_pct=FIRE_TEST_LED_GAIN_PCT` |
| `3` | LED blue | same constants as white, different channel |
| `4` | IR | `duration_ms=FIRE_TEST_IR_DURATION_MS, gain_pct=FIRE_TEST_IR_GAIN_PCT` |
| `?` | — | prints the command menu, fires nothing |

`fire_test_parse_command()` is a plain `switch` on the char, no I/O, returns the enum — this is the
function `test_fire_test.cpp` exercises directly.

`fire_test_service(uint32_t now_ms)`:
1. `if (!Serial.available()) return;` — non-blocking poll, same shape as `geophone_service()`'s
   per-loop-iteration style in `main.cpp`.
2. Read one byte, call `fire_test_parse_command()`.
3. On `kHorn`/`kLedWhite`/`kLedBlue`/`kIr`: build the request struct from the table above, call the
   real driver function (`drive_horn`, `drive_led`, `pulse_ir` — exact signatures already in
   `horn.h`/`led.h`/`ir.h`, don't redeclare them), then print the **full ack**, not just true/false:

   ```cpp
   Serial.print("[firetest] horn allowed=");
   Serial.print(ack.allowed);
   Serial.print(" duration_ms=");
   Serial.print(ack.duration_ms);
   Serial.print(" gain_pct=");
   Serial.print(ack.gain_pct);
   Serial.print(" clamped=");
   Serial.println(ack.clamped);
   ```

   This follows the `[tag] key=value key=value` convention used by `log_trigger()` in
   `state_machine.cpp`, and directly addresses the KNOWN_GAPS note that `ack: bool` alone is too lossy
   to be useful — the harness's whole job is to make clamped/allowed/actual-values visible.
4. On `kHelp` or unrecognized byte: print the four-line command menu.

**Cooldown is expected to refuse repeated commands — this is not a bug.** `rule_gate_apply()` already
enforces `HORN_COOLDOWN_MS=30000`, `LED_COOLDOWN_MS=20000`, `IR_MIN_INTERVAL_MS=5000` per actuator.
Pressing `1` twice inside 30s will print `allowed=false` the second time. Say so explicitly in the
printed menu (`? ` output) so whoever's running the test doesn't think it's broken.

**This call blocks.** `horn.cpp`'s fire sequence is a blocking `delay()` chain (up to
`HORN_BURST_MAX_MS=3000` plus the amp-enable delay); `led.cpp`/`ir.cpp` block for their own
`duration_ms`. During a manual fire-test command, `geophone_service()` and `lora_service()` in the same
`loop()` iteration are blocked too, for up to ~3.15s in the horn case. Acceptable for a bench-only,
human-triggered tool — call this out as a one-line comment in `fire_test.cpp`, don't silently leave it
implicit the way a reviewer would have to go find out for themselves.

## Bench-safe default values — add to `config.h`'s bench-flags block

Same section as `SEISMIC_DEBUG_STREAM_RAW` and friends, same banner discipline (must default to a form
that's safe to ship, rationale comment, "confirm before `sync-to-board.sh`"):

```c
// Manual fire-test harness - serial-command-triggered single fire of
// horn/LED/IR for hardware bring-up verification. Human types a digit into
// App Lab's Serial Monitor; nothing fires without that keystroke, so this
// has no autonomous trigger path. Still gated to 0 by default: the point of
// field builds is that bench-only surface area doesn't exist in them.
#define FIRE_TEST_HARNESS 0

// Bench defaults - short and conservative, real safety backstop is still
// rule_gate_apply()'s per-actuator caps (HORN_GAIN_MAX_PCT etc.), these are
// just sane starting points for a desk-bench test, not a duplicate limit.
#define FIRE_TEST_HORN_DURATION_MS 500   // well under HORN_BURST_MAX_MS=3000
#define FIRE_TEST_HORN_GAIN_PCT 30.0f    // under HORN_GAIN_MAX_PCT=60, desk-volume not field-volume
#define FIRE_TEST_LED_DURATION_MS 1000
#define FIRE_TEST_LED_GAIN_PCT 50.0f
#define FIRE_TEST_IR_DURATION_MS 200     // under IR_PULSE_MAX_MS=500
#define FIRE_TEST_IR_GAIN_PCT 100.0f     // IR is invisible, thermal is the only real constraint
```

## Wiring into `main.cpp`

Same `#if`/`#endif` shape already used for `SEISMIC_DEBUG_STREAM_RAW`'s `Bridge.begin()`/`Bridge.update()`
carve-out — don't invent a different gating style:

```cpp
void setup() {
  Serial.begin(CONSOLE_BAUD);
#if SEISMIC_DEBUG_STREAM_RAW
  Bridge.begin();
#endif
#if FIRE_TEST_HARNESS
  fire_test_init();
#endif
  geophone_init();
  horn_init();
  led_init();
  ir_init();
  lora_init();
  state_machine_init();
}

void loop() {
  const uint32_t now_ms = millis();
#if SEISMIC_DEBUG_STREAM_RAW
  Bridge.update();
#endif
#if FIRE_TEST_HARNESS
  fire_test_service(now_ms);
#endif
  geophone_service();
  lora_service(now_ms);
  state_machine_tick(now_ms);
}
```

`fire_test_init()` can be a no-op or just print the command menu once at boot — your call, keep it
small either way.

## Tests — `test_fire_test/test_fire_test.cpp`

Only `fire_test_parse_command()` is host-testable (it's pure — no `Serial`, no hardware, matches the
"pure core" testing discipline `test_rule_gate.cpp` already follows). The actual fire behavior can only
be verified live on the board via App Lab's browser Serial Monitor — **not** `arduino-cli monitor`,
which ADR 0010's addendum confirms delivers zero bytes even for an unconditional periodic print. Don't
try to test the live fire path from a host build; it's a hardware-session task, not a `pio test` task.

Match `test_rule_gate.cpp`'s exact shape: `#include <unity.h>` first, empty `setUp()`/`tearDown()`,
`static void test_<behavior>(void)` names, `_MESSAGE` assertion variants, every test explicitly listed
in `main()`. Minimum coverage:

- `test_digit_1_maps_to_horn`
- `test_digit_2_maps_to_led_white`
- `test_digit_3_maps_to_led_blue`
- `test_digit_4_maps_to_ir`
- `test_question_mark_maps_to_help`
- `test_unrecognized_byte_maps_to_none`
- `test_whitespace_and_newline_bytes_map_to_none` (Serial Monitor sends a line terminator — make sure
  `\n`/`\r` don't get mis-parsed as a command)

Run with `pio test -e native` from `device/mcu/`, same as the existing suite.

## Docs to update as part of this change

- `docs/KNOWN_GAPS.md`: add a line noting the fire-test harness now exists as the intended mechanism to
  bench-measure `HORN_AMP_ENABLE_DELAY_MS` (currently invented, per the existing gap entry) and to
  sanity-check the provisional burst/cooldown constants — don't mark those gaps closed, just note the
  tool now exists to close them.
- Commit message, Conventional Commits, e.g. `feat(mcu): add serial fire-test harness for horn/led/ir bench verification`.
- No AI/assistant attribution anywhere — commit message, code comments, this spec's own presence
  nowhere referenced in-repo. Standard repo-wide rule, not new to this feature.

## Verification checklist before calling this done

1. `pio test -e native` passes, all seven `test_fire_test` cases plus the existing suite green.
2. `pio run -e native` (or whatever the field-target env is) compiles with `FIRE_TEST_HARNESS 0` —
   confirms the flag truly compiles out, not just logically disabled.
3. Flip to `FIRE_TEST_HARNESS 1` locally, confirm it also compiles.
4. Flash via App Lab (per ADR 0010, the only real flash path), open App Lab's browser Serial Monitor,
   type `1`, confirm the horn fires and the `[firetest]` ack line prints. Repeat for `2`, `3`, `4`.
   Press `1` twice within 30s, confirm the second attempt prints `allowed=false` — that's the cooldown
   gate working, not a failure.
5. Set `FIRE_TEST_HARNESS` back to `0` before this ever goes near `scripts/sync-to-board.sh` for a
   node headed to the field.

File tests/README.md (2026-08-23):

# Tests

Unit, integration, and hardware-in-the-loop tests.

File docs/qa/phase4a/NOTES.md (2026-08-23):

# Phase 4a — Overview screen QA notes

## Automated screenshots

Captured via `scripts/qa-phase4a-screenshots.mjs` against a locally seeded dataset
(`overview_sample.sql`, 7 nodes / 6 health rows / 4 events, one with `vision`
dropped out on the fused decision).

- `overview-desktop.png` / `overview-mobile.png` — default state.
- `overview-node-desktop.png` / `overview-node-mobile.png` — node S7-06 selected,
  digital-twin panel open.

Compared against `docs/design-reference/SectorMap.dc.html` and
`EleTect Platform.dc.html` (lines 745-836): dark CARTO basemap, status pin colors
(green/yellow/red/grey) and the alert ping ring all match. The static mockup's
on-map legend and "N ↑ · 1 km" scale label are superseded by the live
`FleetSummaryTiles` counts above the map (same colors, real numbers) rather than
duplicated on the map itself — a deliberate adaptation for an interactive map vs.
a static illustration, not a fidelity gap.

The dropped-out sensor case renders correctly: S7-06's boar event shows
"Vision — unavailable · dropped out" rather than a fabricated 0%, and the
confidence radar collapses that axis to the centroid instead of plotting a false
point.

## Realtime verification — manual, not automated

An automated polling script (`realtime-check.mjs`, not committed) was used to try
to catch a `nodes.status` update via the live `postgres_changes` subscription.
Across three windows (20s, 90s, 120s — about 4 minutes total) it never detected
the flip, despite the update having actually been run. The script's detection
logic (`text=ALERT` locator → parent `innerText` → string split) was fragile
against the real tile DOM structure; this was a detection-script bug, not a
realtime-feature bug. The script was discarded rather than fixed, since a direct
manual check is stronger evidence anyway.

Manual verification (run by the project owner, screen-observed, not scripted):
logged in as `officer@eletect.in`, ran

```sql
update nodes set status='alert' where id='S7-08';
```

in the Supabase SQL editor while the Overview screen was open in another window.
Observed, side by side, with no page refresh:

- Fleet tiles went from `3 Healthy / 2 Attention / 1 Alert / 1 Offline` to
  `2 Healthy / 2 Attention / 2 Alert / 1 Offline` the instant the SQL editor
  reported "Success. No rows returned."
- The S7-08 pin on the live map turned from green to red and picked up the
  `et-ping` animated ring, matching the alert-state styling used for S7-05.

This confirms the `useRealtimeTable` subscription (`postgres_changes` on
`nodes`, already in the `supabase_realtime` publication) delivers UPDATEs to the
Overview screen live, with both the map marker and the derived fleet-summary
counts reacting correctly. Screenshots of this manual run were shared in chat
but not saved to disk, so they are not checked in — this note stands in as the
verification record.

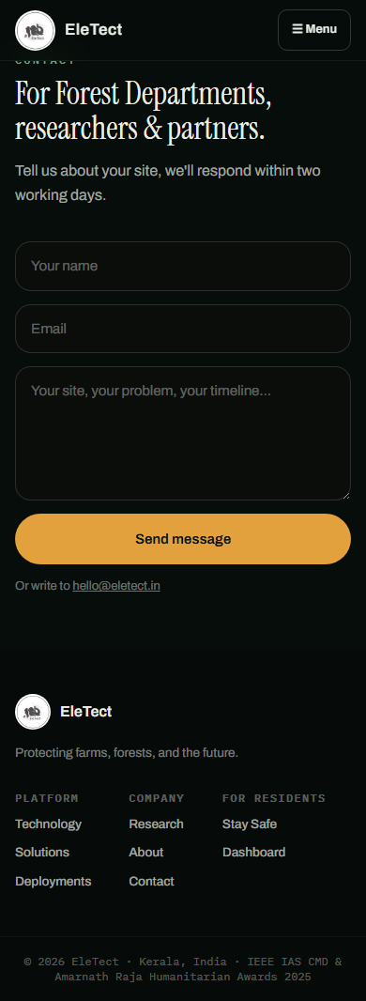
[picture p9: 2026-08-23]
docs/qa/webapp-final/anon-contact-mobile.png

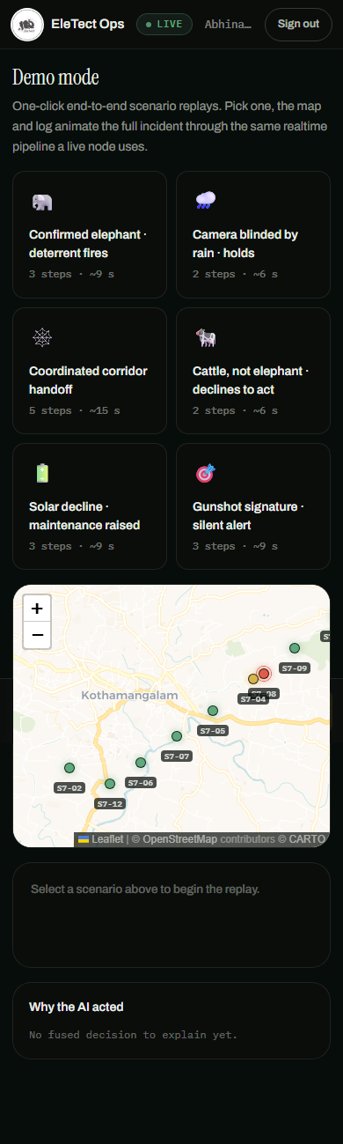
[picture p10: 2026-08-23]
docs/qa/webapp-final/admin-demo-mobile.png

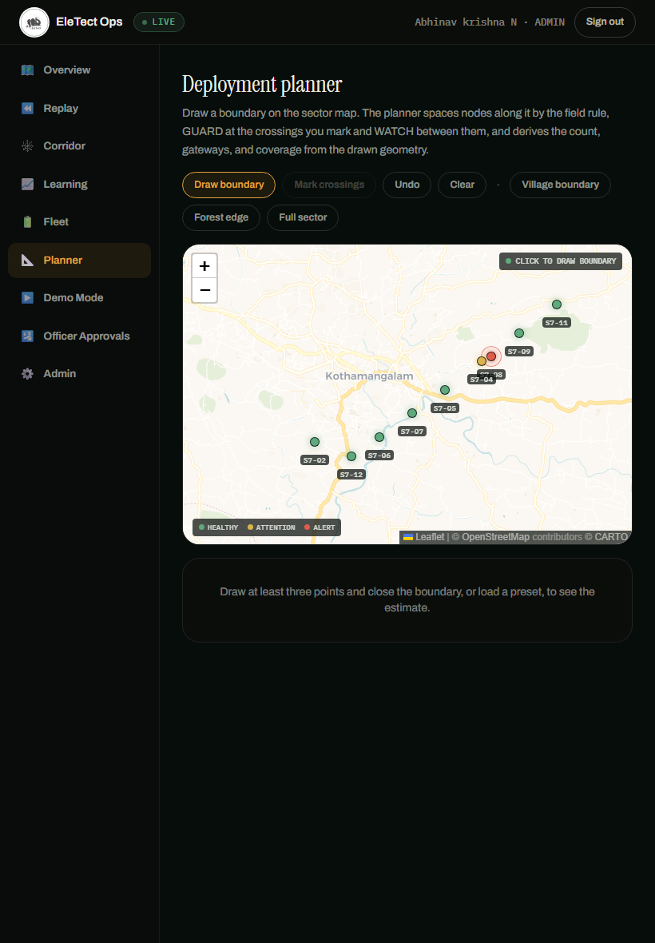
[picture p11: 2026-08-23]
docs/qa/webapp-final/admin-planner-tablet.png

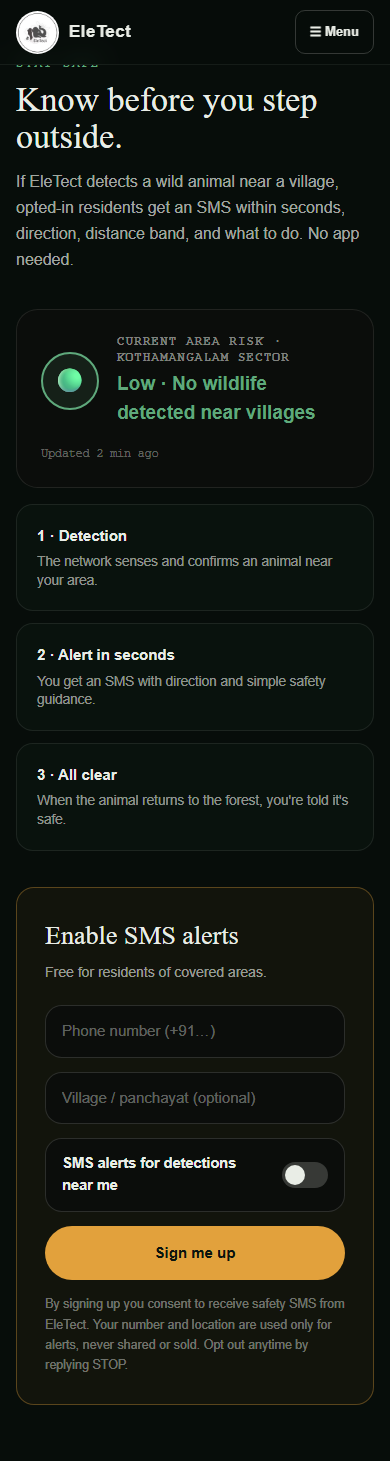
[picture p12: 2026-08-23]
docs/qa/phase2/stay-safe-built-mobile.png

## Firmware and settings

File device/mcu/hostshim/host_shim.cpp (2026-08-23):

// HOST BUILD ONLY - see hostshim/Arduino.h.

#include "Arduino.h"

#include <chrono>
#include <cstdio>
#include <cstring>

#include "Arduino_RouterBridge.h"
#include "Wire.h"

namespace {

constexpr int kMaxPins = 128;
int g_pin_state[kMaxPins] = {};
unsigned long g_millis_offset = 0;

unsigned long steady_millis() {
  using namespace std::chrono;
  static const auto start = steady_clock::now();
  return static_cast<unsigned long>(
      duration_cast<milliseconds>(steady_clock::now() - start).count());
}

}  // namespace

void pinMode(int, int) {}

void digitalWrite(int pin, int value) {
  if (pin >= 0 && pin < kMaxPins) {
    g_pin_state[pin] = value;
  }
}

int digitalRead(int pin) {
  return (pin >= 0 && pin < kMaxPins) ? g_pin_state[pin] : LOW;
}

void analogWrite(int pin, int value) {
  if (pin >= 0 && pin < kMaxPins) {
    g_pin_state[pin] = value;
  }
}

int analogRead(int) { return 0; }

unsigned long millis() { return steady_millis() + g_millis_offset; }

unsigned long micros() { return millis() * 1000UL; }

void delay(unsigned long ms) { g_millis_offset += ms; }

void delayMicroseconds(unsigned int us) { g_millis_offset += us / 1000UL; }

namespace hostshim {

int pin_state(int pin) { return digitalRead(pin); }

void advance_millis(unsigned long ms) { g_millis_offset += ms; }

void reset() {
  std::memset(g_pin_state, 0, sizeof(g_pin_state));
  g_millis_offset = 0;
}

}  // namespace hostshim

size_t Print::write(const uint8_t *buffer, size_t size) {
  size_t written = 0;
  for (size_t i = 0; i < size; ++i) {
    written += write(buffer[i]);
  }
  return written;
}

size_t Print::print(const char *value) {
  return write(reinterpret_cast<const uint8_t *>(value), std::strlen(value));
}

size_t Print::print(char value) { return write(static_cast<uint8_t>(value)); }

size_t Print::print(int value) { return print(static_cast<long>(value)); }

size_t Print::print(unsigned int value) {
  return print(static_cast<unsigned long>(value));
}

size_t Print::print(long value) {
  char buffer[32];
  std::snprintf(buffer, sizeof(buffer), "%ld", value);
  return print(buffer);
}

size_t Print::print(unsigned long value) {
  char buffer[32];
  std::snprintf(buffer, sizeof(buffer), "%lu", value);
  return print(buffer);
}

size_t Print::print(double value, int digits) {
  char buffer[64];
  std::snprintf(buffer, sizeof(buffer), "%.*f", digits, value);
  return print(buffer);
}

size_t Print::println() { return print("\n"); }

size_t Print::println(const char *value) { return print(value) + println(); }

size_t Print::println(char value) { return print(value) + println(); }

size_t Print::println(int value) { return print(value) + println(); }

size_t Print::println(unsigned int value) { return print(value) + println(); }

size_t Print::println(long value) { return print(value) + println(); }

size_t Print::println(unsigned long value) { return print(value) + println(); }

size_t Print::println(double value, int digits) {
  return print(value, digits) + println();
}

void HardwareSerial::begin(unsigned long) {}

void HardwareSerial::end() {}

size_t HardwareSerial::write(uint8_t value) {
  std::fputc(static_cast<int>(value), stdout);
  ++bytes_written_;
  return 1;
}

int HardwareSerial::available() {
  return static_cast<int>(rx_head_ - rx_tail_);
}

int HardwareSerial::read() {
  if (rx_tail_ >= rx_head_) {
    return -1;
  }
  return static_cast<unsigned char>(rx_[rx_tail_++ % kRxCapacity]);
}

int HardwareSerial::peek() {
  if (rx_tail_ >= rx_head_) {
    return -1;
  }
  return static_cast<unsigned char>(rx_[rx_tail_ % kRxCapacity]);
}

void HardwareSerial::flush() { std::fflush(stdout); }

void HardwareSerial::host_feed(const char *bytes) {
  for (const char *p = bytes; *p != '\0'; ++p) {
    rx_[rx_head_++ % kRxCapacity] = *p;
  }
}

HardwareSerial Serial;
HardwareSerial Serial1;

void TwoWire::begin() {}

void TwoWire::setClock(uint32_t) {}

void TwoWire::beginTransmission(uint8_t) {}

size_t TwoWire::write(uint8_t) { return 1; }

size_t TwoWire::write(const uint8_t *, size_t size) { return size; }

uint8_t TwoWire::endTransmission() { return 0; }

uint8_t TwoWire::endTransmission(bool) { return 0; }

uint8_t TwoWire::requestFrom(uint8_t, uint8_t quantity) { return quantity; }

int TwoWire::available() { return static_cast<int>(queue_head_ - queue_tail_); }

int TwoWire::read() {
  if (queue_tail_ >= queue_head_) {
    return 0;  // preserves the original always-0 default when nothing fed.
  }
  return queue_[queue_tail_++ % kQueueCapacity];
}

void TwoWire::host_feed_raw(int16_t raw_value) {
  const uint16_t bits = static_cast<uint16_t>(raw_value);
  queue_[queue_head_++ % kQueueCapacity] = static_cast<uint8_t>(bits >> 8);
  queue_[queue_head_++ % kQueueCapacity] = static_cast<uint8_t>(bits & 0xFF);
}

TwoWire Wire;
TwoWire Wire1;

void BridgeClass::begin() {}

void BridgeClass::update() {}

BridgeClass Bridge;

#ifndef PIO_UNIT_TESTING
// The firmware's entry points are setup()/loop(), which the Arduino Core
// calls on the board. This main() exists only so pio run -e native proves
// the whole src/ tree links and runs against the stub peripherals without
// crashing - the resulting binary is not a runnable node, does no real
// sensing, and is never flashed (see platformio.ini's header banner).
extern void setup();
extern void loop();

int main() {
  std::printf(
      "eletect-mcu host compile check - firmware entry points are "
      "setup()/loop(), built on the board by App Lab.\n");

  setup();
  constexpr int kSmokeIterations = 600;
  for (int i = 0; i < kSmokeIterations; ++i) {
    loop();
  }

  std::printf("host smoke run completed %d loop() iterations without crashing.\n",
              kSmokeIterations);
  return 0;
}
#endif

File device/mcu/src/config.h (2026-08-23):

// EleTect X - MCU configuration.
//
// Single source of every pin assignment, threshold, gain, cooldown and cap on
// the reflex layer (ENGINEERING_CONVENTIONS.md 2). No magic numbers live in
// logic files; if a number matters, it is named here with the reason it holds
// that value.
//
// Pin assignments come from hardware/references/UNO_Q_PINOUT_REFERENCE.md,
// which is a transcription of Arduino's own ABX00162 pinout PDF. Nothing here
// uses the JMISC or JMEDIA advanced headers: they are 1.8 V board-edge
// connectors that need a carrier board we do not have, so they are physically
// inaccessible.

#ifndef CONFIG_H
#define CONFIG_H

#include <stdint.h>

// ---------------------------------------------------------------------------
// Geophone front-end - ADS1115 + INA333 bench stand-in, on I2C2
// ---------------------------------------------------------------------------
// The field design samples the INA333 output on the STM32's own ADC through
// LPBAM (ADR 0009). Until that lands, an ADS1115 breakout carries the same
// signal over I2C. Both satisfy one contract, read_seismic_window(), and
// nothing above the driver knows which is underneath
// (ENGINEERING_CONVENTIONS.md 1).
//
// Wiring is plain male-female jumpers to the breakout's 0.1" pin header, not
// the Qwiic connector: no JST-SH cable is in hand. D20/D21 are I2C2, a bus
// entirely separate from the Qwiic connector's I2C4 (PD12/PD13), so this
// leaves Qwiic free for the BME280/MPU-6050 later.
#define GEOPHONE_I2C_SDA_PIN 20  // PB11, I2C2_SDA (default mapping, no config needed)
#define GEOPHONE_I2C_SCL_PIN 21  // PB10, I2C2_SCL

// CONFIRMED on hardware 2026-08-14: `Wire` is the correct instance for I2C2.
// The arduino:zephyr core declares Wire/Wire1/Wire2/... in the order listed
// by the board overlay's `zephyr,user { i2cs = <&i2c2>, <&i2c4>, <&i2c3>; }`
// (arduino_uno_q_stm32u585xx.overlay) - i2c2 is first, so it is `Wire`, not
// `Wire1` (which binds to i2c4, the Qwiic connector). The generated board
// .dts confirms i2c2's pinctrl-0 is `i2c2_scl_pb10`/`i2c2_sda_pb11` and that
// the node is aliased `arduino_i2c` - i.e. i2c2 is the default Arduino I2C
// header, exactly the PB10/PB11 pins documented above. Cross-checked against
// real bench data: continuous, plausible, varying ADS1115 differential
// readings over the socat/TCP console bridge (not silent, not garbage),
// which is what a correct bus produces - a wrong bus would fail every I2C
// transaction and produce no ring-buffer writes at all.
#define GEOPHONE_I2C_BUS Wire

// 0x48 is the ADS1115 address with ADDR tied to GND - the breakout's default.
#define ADS1115_I2C_ADDRESS 0x48

// 400 kHz fast mode: at 250 SPS the bus is idle almost all the time, but the
// faster clock keeps each conversion read short enough that the I2C timeout
// below can stay tight.
#define GEOPHONE_I2C_CLOCK_HZ 400000UL

// ADS1115 register addresses and config-register fields (datasheet 9.6).
#define ADS1115_REG_CONVERSION 0x00
#define ADS1115_REG_CONFIG 0x01

#define ADS1115_CFG_OS_SINGLE 0x8000        // start a single conversion
#define ADS1115_CFG_MUX_DIFF_0_1 0x0000     // differential AIN0 - AIN1
#define ADS1115_CFG_PGA_2048MV 0x0400       // +/-2.048 V full scale
#define ADS1115_CFG_MODE_CONTINUOUS 0x0000  // free-running, not single-shot
#define ADS1115_CFG_DR_250SPS 0x00A0        // 250 samples per second
#define ADS1115_CFG_COMP_DISABLE 0x0003     // comparator off, ALERT/RDY unused

// ---------------------------------------------------------------------------
// Seismic bench-only debug flags - MUST be 0 before any field sync
// ---------------------------------------------------------------------------
// Every flag in this section exists to support a bench characterization
// session (the INA333 REF-bias check, or a later Part C2 sensitivity/
// waveform-capture pass) and has no role in the field-deployed reflex
// behaviour. All four must read 0 before running scripts/sync-to-board.sh
// against a node that is actually going in the ground - device/mcu/README.md
// documents the sync/re-sync procedure that flips them back.

// When 1, ADS1115_CONFIG_WORD below samples AIN0 single-ended against board
// GND (ADS1115 datasheet 9.6.3, MUX=100) instead of the field differential
// AIN0-AIN1 pair - ADS1115_CFG_MUX_DIFF_0_1 itself is untouched either way.
// This is the INA333 REF-bias bench check (device/mcu/README.md): with VIN+
// shorted to VIN-, differential mode already rejects the INA333's own bias
// rail, so it cannot show whether that bias is centered; single-ended mode
// reads VOUT directly against GND instead, which is the absolute bias level
// the check needs. Left at 0, ADS1115_CFG_MUX_ACTIVE below resolves to
// ADS1115_CFG_MUX_DIFF_0_1 and the field wiring is unaffected.
#define GEOPHONE_DEBUG_SINGLE_ENDED_AIN0 0
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

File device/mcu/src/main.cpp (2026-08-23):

// setup()/loop() shell wiring the reflex-layer subsystems together.
// Bridge.begin()/Bridge.update() are unconditional, production
// infrastructure as of 2026-08-14 - not gated behind SEISMIC_DEBUG_STREAM_RAW
// the way they used to be. That flag still exists and still gates its own
// bench-only raw-sample relay (geophone.cpp), but Bridge itself is no
// longer bench-only: state_machine.cpp's kSensing case needs a real
// Bridge.notify("report_footfall_event", ...) reachable in every field
// build, or every trigger goes right back to producing a bare console
// timestamp and nothing else (docs/KNOWN_GAPS.md's high-severity
// "Raw seismic trigger data does not reach the MPU" entry, 14 Aug). This is
// the resolution to the decision this file's own comment used to defer -
// "decide how the gate should really read once an actuator RPC goes live" -
// see docs/KNOWN_GAPS.md for the full writeup.
//
// device/mpu/bridge/schema.md's MPU->MCU handlers (drive_horn, drive_led,
// pulse_ir, get_system_state, send_lora_alert) have real adapters in
// bridge_handlers.cpp, but their Bridge.provide() calls below stay
// deliberately commented out - see
// docs/KNOWN_GAPS.md for why that is deferred to a hardware session, one
// function at a time. Bridge.begin()/Bridge.update() running unconditionally
// does not change that discipline: it makes the notify direction reachable,
// it does not register any provide() handler.

#include "Arduino.h"
#include "Arduino_RouterBridge.h"
#include "bridge_handlers.h"
#include "config.h"
#include "fire_test.h"
#include "geophone.h"
#include "horn.h"
#include "ir.h"
#include "led.h"
#include "mac.h"
#include "state_machine.h"

void setup() {
  Serial.begin(CONSOLE_BAUD);

  Bridge.begin();

  // NOT REGISTERED - see bridge_handlers.h and docs/KNOWN_GAPS.md. Each
  // line below wires one MPU->MCU function from device/mpu/bridge/
  // schema.md to its adapter in bridge_handlers.cpp.
  // docs/DEVICE_DEVELOPMENT_WORKFLOW.md 3 / ENGINEERING_CONVENTIONS.md 8:
  // registering an additional Bridge.provide() has broken every
  // previously-working one on the same sketch in this project's own
  // history - uncomment exactly ONE line per hardware session, flash,
  // and confirm every already-registered function (including
  // debug_stream_raw_seismic_sample, geophone.cpp) still works before
  // uncommenting the next. Never uncomment more than one at a time, and
  // never as part of a routine sync-to-board.sh push.
  //
  // Bridge.begin()/Bridge.update() are unconditional now (see this file's
  // top comment), so that is no longer what gates these four - only the
  // one-at-a-time hardware-verification discipline above does.
  // Bridge.provide("drive_horn", bridge_drive_horn);
  // Bridge.provide("drive_led", bridge_drive_led);
  // Bridge.provide("pulse_ir", bridge_pulse_ir);
  // Bridge.provide("get_system_state", bridge_get_system_state);
  // Bridge.provide("send_lora_alert", bridge_send_lora_alert);

#if FIRE_TEST_HARNESS
  fire_test_init();
#endif

  geophone_init();
  horn_init();
  led_init();
  ir_init();
  lora_init();
  state_machine_init();
}

void loop() {
  const uint32_t now_ms = millis();

  Bridge.update();

#if FIRE_TEST_HARNESS
  fire_test_service(now_ms);
#endif

  // Serviced every iteration regardless of reflex state: the geophone ring
  // buffer must keep filling even while the state machine sits in EVENT or
  // COOLDOWN, and the LoRa join state machine must keep advancing
  // independently of sensing.
  geophone_service();
  lora_service(now_ms);

  state_machine_tick(now_ms);
}

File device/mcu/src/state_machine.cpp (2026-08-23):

#include "state_machine.h"

#include <array>

#include "Arduino.h"
#include "Arduino_RouterBridge.h"
#include "config.h"
#include "footfall_features.h"
#include "geophone.h"
#include "sta_lta.h"

namespace {

reflex_state g_state = reflex_state::kIdle;
uint32_t g_state_entered_ms = 0;

void enter(reflex_state next, uint32_t now_ms) {
  g_state = next;
  g_state_entered_ms = now_ms;
}

// rollover-safe, same pattern as rule_gate_apply().
uint32_t elapsed_since_entry(uint32_t now_ms) { return now_ms - g_state_entered_ms; }

#if SEISMIC_TRIGGER_CONSOLE_LOG
void log_trigger(const sta_lta_result &result, uint32_t now_ms) {
  // Format fixed by device/mcu/README.md's bench stomp-test procedure - keep
  // this line and that doc in sync if either changes. Gated behind
  // SEISMIC_TRIGGER_CONSOLE_LOG (config.h) - see that flag's comment and
  // docs/KNOWN_GAPS.md's 18 Aug entry: this print shares a physical wire
  // with LoRa AT traffic (LORA_SERIAL) and must stay silent in the field.
  Serial.print("[trigger] t=");
  Serial.print(now_ms);
  Serial.print(" sta=");
  Serial.print(result.sta);
  Serial.print(" lta=");
  Serial.print(result.lta);
  Serial.print(" ratio=");
  Serial.print(result.peak_ratio);
  Serial.print(" idx=");
  Serial.println(static_cast<unsigned long>(result.trigger_index));
}
#endif  // SEISMIC_TRIGGER_CONSOLE_LOG

// The real MCU->MPU notify for every trigger (device/mpu/bridge/schema.md:
// report_footfall_event) - the fix for docs/KNOWN_GAPS.md's high-severity
// "raw trigger data does not reach the MPU" gap (14 Aug). probability and
// feature_vector are footfall_features.cpp's honest placeholder derivation
// from this same result/window, not a real TinyML model output yet (see
// that file's own header). Bridge.notify() is fire-and-forget - confirmed
// by reading the real installed Arduino_RouterBridge bridge.h directly
// (docs/KNOWN_GAPS.md, Build-call 5): it takes a write mutex and returns
// after a one-way send, never blocking this loop on an MPU reply.
void notify_footfall_event(const float *window, const sta_lta_result &result, uint32_t now_ms) {
  const float probability = footfall_probability_from_ratio(result.peak_ratio);
  std::array<float, 8> feature_vector{};
  footfall_feature_vector(window, SEISMIC_WINDOW_SAMPLES, result, feature_vector.data());

  Bridge.notify("report_footfall_event", static_cast<uint8_t>(BRIDGE_SCHEMA_VERSION), probability,
                result.peak_ratio, feature_vector);

#if SEISMIC_TRIGGER_CONSOLE_LOG
  // Gated same as log_trigger() above and for the same reason - the real
  // Bridge.notify() call above is untouched, this is only its console echo.
  Serial.print("[notify] t=");
  Serial.print(now_ms);
  Serial.print(" report_footfall_event probability=");
  Serial.print(probability, 4);
  Serial.print(" sta_lta_ratio=");
  Serial.println(result.peak_ratio);
#else
  (void)now_ms;  // now_ms's only consumer is the console echo gated above.
#endif
}

#if SEISMIC_DEBUG_VERBOSE
// Bench-only: sta/lta/ratio on a fixed cadence, independent of whether a
// trigger fires - the [trigger] line above only exists at the moment of a
// crossing, which says nothing about where the ratio sits the rest of the
// time. Rate-limited the same way geophone.cpp's [bias-check] line is.
void log_verbose_ratio(const sta_lta_result &result, uint32_t now_ms) {
  static uint32_t s_last_verbose_print_ms = 0;
  if (now_ms - s_last_verbose_print_ms < SEISMIC_DEBUG_PRINT_INTERVAL_MS) {
    return;
  }
  s_last_verbose_print_ms = now_ms;
  Serial.print("[seismic] t=");
  Serial.print(now_ms);
  Serial.print(" sta=");
  Serial.print(result.sta);
  Serial.print(" lta=");
  Serial.print(result.lta);
  Serial.print(" ratio=");
  Serial.println(result.peak_ratio);
}

// Bench-only, demo visual aid: reruns the same read+detect kSensing's own
// case below already does, purely so this console's ratio line stays alive
// through EVENT/COOLDOWN instead of going dark for the whole dead zone - the
// real reflex logic never sees this call or its result, it only acts on the
// copy computed inside the kSensing case, so the "don't re-trigger mid-event"
// gating this function's caller sits outside of is completely unaffected by
// this existing.
void log_verbose_ratio_now(uint32_t now_ms) {
  float window[SEISMIC_WINDOW_SAMPLES];
  read_seismic_window(window);
  const sta_lta_result result = sta_lta_detect(window, SEISMIC_WINDOW_SAMPLES, STA_SAMPLES,
                                                LTA_SAMPLES, STA_LTA_TRIGGER_RATIO);
  log_verbose_ratio(result, now_ms);
}

// Bench-only: the raw window as CSV volts, for scripts/plot_seismic_window.py
// to render - Part C2's sensitivity/waveform-characterization pass, not the
// REF-bias check. Fires alongside every existing [trigger] line, not on its
// own timer - a trigger is already the interesting moment to keep the trace
// for.
void log_window_csv(const float *window, size_t n, uint32_t now_ms) {
  Serial.print("[window] t=");
  Serial.print(now_ms);
  Serial.print(" n=");
  Serial.print(static_cast<unsigned long>(n));
  Serial.print(" rate_hz=");
  Serial.print(SEISMIC_SAMPLE_RATE_HZ);
  Serial.println(" unit=volts");
  for (size_t i = 0; i < n; ++i) {
    Serial.print(window[i], 6);
    if (i + 1 < n) {
      Serial.print(",");
    }
  }
  Serial.println();
}
#endif  // SEISMIC_DEBUG_VERBOSE

}  // namespace

void state_machine_init() { enter(reflex_state::kIdle, millis()); }
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
